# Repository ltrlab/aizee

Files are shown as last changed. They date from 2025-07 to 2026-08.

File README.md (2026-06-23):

# AIZEE — open-source mobile manipulation platform

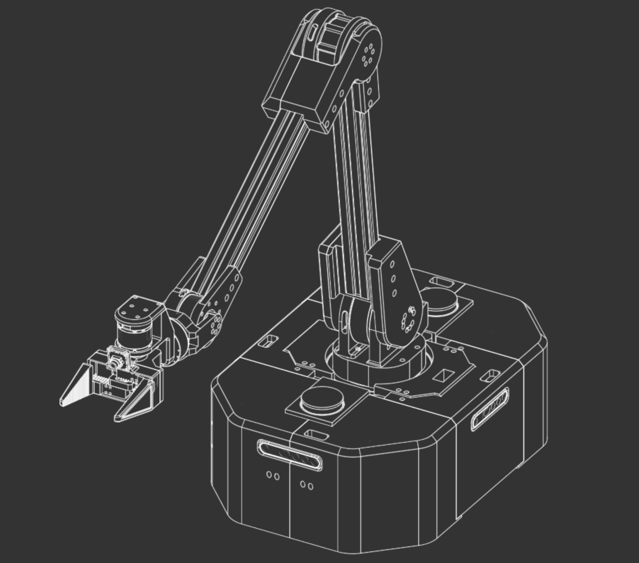
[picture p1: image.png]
AIZEE preview


AIZEE is a wheeled mobile manipulator with a 6-DoF arm, built for real-time
teleoperation, demonstration collection, and imitation-learning policies. It
pairs a deterministic Rust motor-control core with a Python teleop/learning
stack, all glued together over ZeroMQ.

- **CAD (OnShape):** https://cad.onshape.com/documents/191b8a861f2900918f30776f/w/8fcf08900b23701d0eff1c6a/e/fcb77dc7adbafb5b753006f3

> The platform runs in two physical configurations that share the same code and
> CAN bus: **rover mode** (drive wheels + arm) and **static mode** (arm only on a
> fixed stand, typically with the external scene camera). Optional subsystems
> auto-detect at runtime, so the same launch command works in either mode.

---

## Hardware

### Compute
- **NVIDIA Jetson Orin Nano** (JetPack 6.x) — the on-robot brain. Runs the Rust
  motor-control binary, the camera/UPS/display nodes, and the status dashboard.
  USB-CAN (gs_usb) adapter on `can1`; ZeroMQ for all inter-process messaging.
- **Operator / dev machine** — runs teleop, demonstration collection, and
  training. Drives the arm through a *leader* device (see below) and connects to
  the Jetson over one of three network paths.

### Actuation — 9× ROBSTRIDE motors (single CAN bus, `can1`)

| Joint | CAN ID | Motor | Role |
|---|:---:|:---:|---|
| left_wheel | 0x02 | ROBSTRIDE04 | drive wheel |
| right_wheel| 0x04 | ROBSTRIDE04 | drive wheel |
| swivel | 0x03 | ROBSTRIDE03 | base rotation (arm joint 0) |
| gantry_base| 0x05 | ROBSTRIDE04 | shoulder |
| gantry_mid | 0x06 | ROBSTRIDE03 | upper arm |
| gantry_end | 0x07 | ROBSTRIDE02 | elbow |
| wrist_pitch| 0x08 | ROBSTRIDE02 | wrist pitch |
| wrist_roll | 0x09 | ROBSTRIDE00 | wrist roll |
| gripper | 0x0A | ROBSTRIDE00 | gripper |

The arm is **7-DoF in software** (`swivel` + 6-DoF gantry, swivel-first
ordering). In static mode the two wheels are simply absent from the bus.

**Control loops** (`config/hardware_jetson_rover.yaml`):
- Arm: **400 Hz** (CAN-bus limited — ~280 µs per motor round-trip)
- Base (wheels + swivel): **100 Hz**
- Telemetry publish: **50 Hz**
- Watchdog: holds position if no command for **500 ms**

### Cameras
- **Gripper camera** — ELP-USBFHD01M-L21 USB UVC, color **1024×768 @ 30 fps**
  (MJPG), mounted on the gripper. Primary close-up training observation.
- **Scene camera** *(optional)* — Intel RealSense D435/D435i/D455, color +
  depth **640×480 @ 15 fps**, externally mounted for a wider workspace view with
  depth. Auto-detected at runtime: present ⇒ static mode (recorded), absent ⇒
  rover mode (hidden, not required).

### Other sensors & peripherals
- **2× SLAMTEC RPLiDAR A1M8** — 360° scan, driver in `rust/lidar_control`
  (optional; not enabled in all configurations).
- **UPS power monitor** — Waveshare INA219 over I²C, publishes battery
  voltage/current/% telemetry.
- **Tufty2040 status display** — RP2040 over USB CDC, on-robot status readout.
- **Wireless e-stop** — ESP32 ESP-NOW receiver bridged to ZMQ; broadcasts stop
  to all motors.

### Networking — three ways to reach the robot
| Path | Jetson address | Use |
|---|---|-----|
| LAN / WiFi client | `192.168.0.27` | production network (configured default) |
| USB-C ethernet | `10.42.0.1` | direct tether (NetworkManager shared link) |
| WiFi AP `aizee` | `192.168.50.1` | the robot broadcasts its own network (AP mode) |

The operator tools probe these **in priority order** and use the first that
answers, so the same command works whether you're on the LAN, tethered over
USB-C, or joined to the robot's own WiFi.

---

## Software

### Stack
- **Rust** — motor control, CAN protocol, deterministic control loops, CAN
  fault recovery.
- **Python 3.10+** — teleop, leader drivers, camera/UPS/display nodes,
  demonstration collection, policy training & inference.
- **ZeroMQ** — command/telemetry/camera pub-sub between host and Jetson.
- **Rerun** — real-time visualization and MCAP logging.

### Architecture
```
        Operator / dev machine
  ┌───────────────────────────────────┐
  │ leader arm (SO-101 / OpenRB-150 /  │
  │ Quest VR) · gamepad · M5 joystick  │
  │ collect_demo.py / teleop.py        │
  └───────────────┬───────────────────┘
                  │ ZMQ commands (~100 Hz)
                  │ path: 192.168.0.27 → 10.42.0.1 → 192.168.50.1
                  ▼
  ┌───────────────────────────────────────────────┐
  │              Jetson Orin Nano                   │
  │  motor_control (Rust)      400 Hz arm /100 Hz  │
  │    CAN bus · watchdog · fault recovery         │
  │      ├─ telemetry  PUB :5556  (50 Hz)          │
  │  camera_node (gripper UVC) PUB :5563           │
  │  camera_node (scene RGB-D) PUB :5564           │
  │  ups_node                  PUB :5562           │
  │  lidar_control             PUB :5561           │
  │  heartbeat dashboard       HTTP :8088          │
  └───────────────────────────────────────────────┘
```

### ZeroMQ / service ports
| Port | Type | Service | Payload |
|:----:|---|---|---|
| 5555 | SUB | motor_control | incoming motor commands |
| 5556 | PUB | motor_control | motor telemetry (state/pos/vel/torque/temp) |
| 5561 | PUB | lidar_control | LiDAR scans |
| 5562 | PUB | ups_node | battery telemetry |
| 5563 | PUB | gripper camera | color JPEG |
| 5573 | REP | gripper camera | runtime V4L2 control (GUI sliders) |
| 5564 | PUB | scene camera | color JPEG + Z16 depth |
| 8088 | HTTP | heartbeat | status/telemetry/log dashboard |

On-robot subsystems run as **systemd services** (`aizee-motor-control-rover`,
`aizee-gripper-cam`, `aizee-scene-cam`, `aizee-ups-monitor`, `aizee-heartbeat`,
`aizee-display`, …) and start on boot.

---

## Repository structure
```
aizee/
├── rust/
│   ├── motor_control/   # CAN driver + control loops (400 Hz arm, 100 Hz base) + recovery
│   ├── comms/           # ZeroMQ abstractions and message schemas
│   ├── lidar_control/   # RPLiDAR A1M8 dual-sensor driver
│   └── bindings/        # PyO3 Python bindings (reserved)
├── python/
│   ├── teleop/          # Leader drivers: SO-101, OpenRB-150, Quest VR + shared discovery
│   ├── nodes/           # Camera, UPS, ACT-policy inference nodes
│   ├── scripts/         # collect_demo (GUI), teleop, leader monitor, episode replay/view
│   ├── training/        # ACT + ACT-JEPA policy training and dataset utilities
│   ├── tools/           # heartbeat_server.py (status dashboard)
│   └── web/             # WebXR client for Quest teleop
├── config/              # Hardware YAML, calibration, systemd/udev units
├── scripts/             # Deploy, setup, and diagnostic shell scripts
├── firmware/            # Tufty2040 display, wireless e-stop, OpenRB-150 leader
├── urdf/                # Robot URDF (from OnShape)
├── episodes/            # Recorded demonstrations (HDF5)
├── docs/                # Quick-start, subsystem, and learning-pipeline docs
└── tests/               # Test suite
```

---

## Getting started

### Prerequisites
- NVIDIA Jetson Orin Nano with JetPack 6.x
- Rust toolchain (stable) and Python 3.10+
- A leader device for teleop (SO-101, OpenRB-150, or a Meta Quest headset) —
  optional; the stack also runs leaderless and hot-plugs a leader later.

### Install & deploy
```bash
git clone https://github.com/ltrlab/aizee.git
cd aizee
pip install -r requirements.txt

# Deploy to the Jetson (motor control + services)
./scripts/deploy_jetson_rover.sh

# Deploy optional subsystems
./scripts/deploy_gripper_camera.sh
./scripts/deploy_scene_cam.sh      # static mode only
./scripts/deploy_heartbeat.sh
```

### Check the robot is up
Open the **heartbeat dashboard** — service status, recent logs, host metrics,
and live robot telemetry (motors, batteries, cameras) on one page:
```
http://10.42.0.1:8088     # over USB-C ethernet
http://192.168.50.1:8088  # over the robot's WiFi AP
```

### Teleoperate
```bash
# Full teleop (gamepad / keyboard)
python python/teleop/teleop.py

# SO-101 leader-arm teleop
python python/scripts/so101_teleop.py --port /dev/ttyACM0

# Live leader position/limits monitor (auto-detects SO-101 or OpenRB-150)
python python/scripts/leader_monitor.py
```

### Collect demonstrations & train
```bash
# Record demos — leader auto-detected on USB; rover-IP auto-resolved;
# scene cam auto-detected (omit it for rover mode)
python python/scripts/collect_demo.py --gui

# Force a specific leader kind
python python/scripts/collect_demo.py --gui --leader openrb

# Train an ACT policy on collected episodes
python python/training/train.py --data-dir episodes/ --output-dir checkpoints/

# (Experimental) ACT-JEPA — adds a self-supervised world-model objective
python python/training/train_jepa.py --data-dir episodes/ --output-dir checkpoints/

# Run a trained policy on the arm
python python/nodes/act_policy_node.py --checkpoint checkpoints/act_epoch_0100.pt

# Visualize / replay a recorded episode
python python/scripts/view_episode.py episodes/episode_0001.hdf5
python python/scripts/episode_replay_live.py episodes/episode_0001.hdf5
```

### Leader devices
All three present the same 7-DoF interface, so teleop/collection code is
leader-agnostic once connected:
- **SO-101** — Feetech STS3215 servo arm over USB serial (original leader).
- **OpenRB-150 + Dynamixel XL330** — drop-in alternative; also carries an
  M5Stack Joystick2 for drive + record-toggle.
- **Quest VR** — Meta Quest Pro driving the arm via a WebXR client (`python/web`).

---

## Data format
Demonstrations are written as HDF5:
- **v4** — gripper camera + joint states/commands/torques + timestamps.
- **v5** — v4 **plus** `observations/images/scene` and `timestamps/camera_scene`
  when the scene camera is present. v4 episodes remain fully loadable.

---

## Status
All major subsystems are deployed and operational:
- ✅ Rust motor control (400 Hz arm / 100 Hz base) with CAN fault recovery
- ✅ Drive wheels + 6-DoF arm on one CAN bus (rover & static modes)
- ✅ Teleop via SO-101, OpenRB-150, and Quest VR leaders (7-DoF)
- ✅ On-Jetson cameras: ELP UVC gripper + RealSense scene (udev auto-start)
- ✅ Demonstration collection with camera sync (HDF5 v4/v5) + GUI
- ✅ ACT policy training & inference; ACT-JEPA training (experimental)
- ✅ Episode replay with safety clamping
- ✅ UPS battery monitoring, Tufty status display, wireless e-stop
- ✅ WiFi AP mode + status/telemetry dashboard
- ◻️ 2× RPLiDAR A1M8 integration (driver present; not always enabled)

See [docs/PHASES.md](docs/PHASES.md) for the full roadmap.

---

## Documentation
- [docs/quickstart/](docs/quickstart/) — connect, run, and post-reboot guides
- [docs/subsystems/](docs/subsystems/) — motors, cameras, leaders, UPS, display, LiDAR
- [docs/LEARNING_PIPELINE.md](docs/LEARNING_PIPELINE.md) — calibration → collection → training → deployment
- [docs/PHASES.md](docs/PHASES.md) — implementation roadmap

## License
MIT — see [LICENSE](LICENSE).

## Contributing
Active research project — contributions welcome.

## Contact
LTRLABS — [GitHub](https://github.com/ltrlab)

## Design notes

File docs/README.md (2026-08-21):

# AIZEE Documentation

Technical documentation for the AIZEE mobile manipulation platform.

## Getting started
- **[quickstart/FRESH_JETSON_SETUP.md](quickstart/FRESH_JETSON_SETUP.md)** — blank Orin Nano → validated robot (`scripts/bootstrap_jetson.sh` + the `/setup` wizard)
- **[quickstart/JETSON_QUICK_START.md](quickstart/JETSON_QUICK_START.md)** — connect to the robot and run teleop / data collection (daily reference)
- **[quickstart/QUICK_START_AFTER_REBOOT.md](quickstart/QUICK_START_AFTER_REBOOT.md)** — post-reboot verification, service management, troubleshooting

> First check after connecting: the **heartbeat dashboard** at `http://<jetson-ip>:8088`
> (e.g. `http://10.42.0.1:8088` over USB-C, `http://192.168.50.1:8088` over the `aizee` AP) —
> service status, recent logs, host metrics, and live robot telemetry on one page.

## Subsystems
- **[subsystems/MOTORS.md](subsystems/MOTORS.md)** — 9× ROBSTRIDE on `can1`; roster/CAN IDs, control loops, parameter read/write protocol
- **[subsystems/CAMERAS.md](subsystems/CAMERAS.md)** — gripper UVC (primary) + optional RealSense scene cam, both on the Jetson
- **[subsystems/OPENRB_LEADER.md](subsystems/OPENRB_LEADER.md)** — OpenRB-150 + Dynamixel XL330 leader: firmware, setup, wire protocol
- **[subsystems/UPS.md](subsystems/UPS.md)** — INA219 battery monitoring
- **[subsystems/TUFTY2040.md](subsystems/TUFTY2040.md)** — Tufty2040 status display
- **[subsystems/LIDAR.md](subsystems/LIDAR.md)** — 2× RPLiDAR A1M8 (optional)

## Learning
- **[LEARNING_PIPELINE.md](LEARNING_PIPELINE.md)** — end-to-end guide: calibration → data collection → training → evaluation → deployment
- **[learning/RESEARCH_PLAN.md](learning/RESEARCH_PLAN.md)** — research direction and experiment plan

## Roadmap
- **[PHASES.md](PHASES.md)** — implementation status and roadmap

## Reference
- **[MINERVA_ACTUATORS.md](MINERVA_ACTUATORS.md)** — Cubemars actuator plan for the Minerva humanoid torso + cost/weight comparison vs the AIZEE Robstrides
- ROBSTRIDE motor manuals: `RS00`/`RS02`/`RS03`/`RS04` User Manual PDFs (this directory)
- [../rust/motor_control/README.md](../rust/motor_control/README.md) — motor control crate
- [../rust/lidar_control/README.md](../rust/lidar_control/README.md) — LiDAR control crate
- [../tests/README.md](../tests/README.md) — test suite
- [../README.md](../README.md) — project overview & hardware specs

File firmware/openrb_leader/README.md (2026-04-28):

# OpenRB-150 Leader Arm Firmware

Reads 7× Dynamixel XL330-M077-T servos and exposes them to the host over
USB-CDC for use as the AIZEE leader arm. See
[../../docs/subsystems/OPENRB_LEADER.md](../../docs/subsystems/OPENRB_LEADER.md)
for full documentation including wire protocol and setup procedure.

## Build / upload

```bash
pip install --user platformio
pio run -e openrb150 -t upload --upload-port COM4 -d firmware/openrb_leader
```

The `openrb150_bsp/` folder vendors the Robotis OpenRB-150 SAMD Arduino
core (LGPL-2.1) so the build is self-contained — no Arduino IDE required.

## Layout

```
firmware/openrb_leader/
├── platformio.ini              # PlatformIO build config (overrides framework with the vendored BSP)
├── boards/openrb150.json       # Custom PIO board definition for OpenRB-150
├── src/main.cpp                # Sketch — wire protocol, sync-read, setup commands
├── openrb150_bsp/              # Vendored Robotis OpenRB-150 Arduino SAMD core
└── README.md                   # This file
```

## Host-side scripts

| Script | Purpose |
|---|---|
| `python/scripts/openrb_setup_arm.py` | First-time servo ID assignment (1..7) |
| `python/scripts/openrb_calibrate.py` | Per-joint min/max calibration |
| `python/scripts/leader_monitor.py` | Live position + limits monitor (also drives `C` key for sequential centering) |

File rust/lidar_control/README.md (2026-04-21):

# lidar_control - RPLiDAR A1M8 Interface

Rust service for interfacing with RPLiDAR A1M8 sensors on the AIZEE rover.

## Overview

This crate provides a standalone service that:
- Interfaces with two RPLiDAR A1M8 sensors via USB serial
- Publishes scan data via ZeroMQ on port 5561
- Runs independently from motor control for failure isolation
- Supports automatic reconnection on USB disconnect
- Uses async Tokio with `spawn_blocking` for serial I/O

## Architecture

```
┌─────────────────────────────────────────────────────┐
│                  lidar_control                      │
│                                                     │
│  ┌──────────────┐      ┌──────────────┐           │
│  │ LidarScanner │      │ LidarScanner │           │
│  │   (front)    │      │   (back)     │           │
│  └──────┬───────┘      └──────┬───────┘           │
│         │                     │                    │
│         │ spawn_blocking      │ spawn_blocking     │
│         │                     │                    │
│         └─────────┬───────────┘                    │
│                   │                                │
│            mpsc::channel                           │
│                   │                                │
│                   ▼                                │
│          ┌─────────────────┐                       │
│          │  Main Loop      │                       │
│          │  (async tokio)  │                       │
│          └────────┬────────┘                       │
│                   │                                │
│                   ▼                                │
│          ┌─────────────────┐                       │
│          │   ZMQ PUB       │                       │
│          │   tcp://*:5561  │                       │
│          └─────────────────┘                       │
└─────────────────────────────────────────────────────┘
```

## Message Format

Published as `TelemetryMessage` JSON on ZMQ port 5561:

```json
{
  "timestamp": 1707584123.456,
  "motors": {},
  "battery_voltage": null,
  "lidar_scans": [
    {
      "sensor_id": "lidar_front",
      "angle_min": 0.0,
      "angle_max": 6.283185,
      "angle_increment": 0.017453,
      "range_min": 0.15,
      "range_max": 12.0,
      "ranges": [1.23, 2.45, 3.67, ...],
      "intensities": [255, 248, 250, ...]
    },
    {
      "sensor_id": "lidar_back",
      "angle_min": 0.0,
      "angle_max": 6.283185,
      "angle_increment": 0.017453,
      "range_min": 0.15,
      "range_max": 12.0,
      "ranges": [0.89, 1.56, 2.34, ...],
      "intensities": [252, 255, 249, ...]
    }
  ]
}
```

## Configuration

Configured via `config/hardware_jetson_rover.yaml`:

```yaml
lidars:
  - id: lidar_front
    device: /dev/rplidar_front
    scan_mode: standard

  - id: lidar_back
    device: /dev/rplidar_back
    scan_mode: standard

network:
  device:
    zmq:
      lidar_pub: "tcp://*:5561"
```

## Building

```bash
# Build release binary
cargo build --release -p lidar_control

# Binary location
./target/release/lidar_control
```

## Running

```bash
# Set config path
export AIZEE_CONFIG=/path/to/config/hardware_jetson_rover.yaml

# Set log level (optional)
export RUST_LOG=info

# Run
./target/release/lidar_control
```

## Dependencies

- **rplidar_drv** (0.6): RPLiDAR SDK bindings
- **serialport** (4.2): Cross-platform serial port access
- **tokio**: Async runtime
- **zmq**: ZeroMQ bindings
- **comms**: Internal crate (message definitions)

## Error Handling

The service is designed for robustness:

1. **Independent sensors**: One sensor failing doesn't crash the other
2. **Auto-reconnect**: USB disconnect triggers reconnection attempts
3. **Graceful degradation**: Continues operating with one sensor if other fails
4. **Blocking I/O isolation**: Serial I/O runs in `spawn_blocking` threads

## Testing

Subscribe to telemetry with Python:

```python
import zmq

ctx = zmq.Context()
sub = ctx.socket(zmq.SUB)
sub.connect("tcp://192.168.0.27:5561")
sub.subscribe(b"")

msg = sub.recv_json()
print(f"Received {len(msg['lidar_scans'])} scans")
```

## Deployment

See `docs/subsystems/LIDAR.md` for complete deployment guide.

## Performance

- **Scan rate**: ~5.5Hz (natural RPLiDAR A1M8 rate)
- **Publish rate**: 5Hz (200ms interval)
- **Points per scan**: 350-365
- **CPU usage**: <5% per sensor
- **Memory**: ~8-12 MB

## Module Structure

- `main.rs`: Tokio runtime, ZMQ publisher, main control loop
- `scanner.rs`: `LidarScanner` struct, hardware interface, reconnect logic

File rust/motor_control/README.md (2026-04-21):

# AIZEE Motor Control

Low-level CAN bus motor control for ROBSTRIDE actuators with deterministic control loops.

## Features

- **ROBSTRIDE Protocol**: Complete implementation of RS03-EN CAN protocol
- **Deterministic Control**: 1kHz arm control loop, 100Hz base control loop
- **Safety Features**: Watchdog timeout, soft limits, emergency stop
- **ZeroMQ Interface**: JSON commands over pub/sub sockets
- **Real-time Telemetry**: 50Hz motor state publishing

## Building

```bash
cd rust/motor_control
cargo build --release
```

## CAN Interface Setup

### For CANable/slcan Adapters

```bash
# Load slcan kernel module
sudo modprobe slcan

# Attach slcan device (replace /dev/ttyACM0 with your adapter)
sudo slcand -o -c -s8 /dev/ttyACM0 can0

# Bring up the interface
sudo ip link set can0 up

# Verify
ip link show can0
```

### For SocketCAN Native Interfaces

On the Jetson Orin Nano (production), motors are on `can1`:

```bash
# Set bitrate to 1 Mbps
sudo ip link set can1 type can bitrate 1000000

# Bring up the interface
sudo ip link set can1 up

# Verify
ip link show can1
```

## Running

```bash
# Set config path (optional, defaults to config/hardware.yaml)
export AIZEE_CONFIG=config/hardware.yaml

# Run motor controller
./target/release/motor_control
```

## Configuration

Edit `config/hardware.yaml` to match your hardware:

```yaml
motors:
  wheels:
    - id: left_wheel
      can_id: 0x01
      type: ROBSTRIDE04
      # ...

can:
  interface: can1  # Jetson production: can1; RPi4 arm module: can0

network:
  device:  # accepts "jetson" as alias for backward compatibility
    zmq:
      command_sub: "tcp://*:5555"
      telemetry_pub: "tcp://*:5556"
```

## Command Interface

Send JSON commands to `tcp://localhost:5555`:

### Enable Motors
```json
{
  "type": "enable",
  "motor_ids": ["left_wheel", "right_wheel"]
}
```

### Drive Base
```json
{
  "type": "drive",
  "linear": 0.5,
  "angular": 0.2
}
```

### Move Arm
```json
{
  "type": "arm_joints",
  "positions": [0.1, 0.5, -0.3],
  "velocities": [0.0, 0.0, 0.0]
}
```

### Emergency Stop
```json
{
  "type": "emergency_stop"
}
```

## Telemetry Format

Receive JSON telemetry from `tcp://localhost:5556`:

```json
{
  "timestamp": 1234567890.123,
  "motors": {
    "left_wheel": {
      "position": 1.5,
      "velocity": 0.5,
      "torque": 2.1,
      "temperature": 45.0,
      "error": null
    }
  }
}
```

## Testing

Use the Python test script:

```bash
# Interactive mode
python python/teleop/simple_test.py

# Automated test sequence
python python/teleop/simple_test.py auto
```

## Troubleshooting

### CAN Interface Not Found

```bash
# Check available interfaces
ip link show

# For slcan adapters, check USB connection
lsusb
ls /dev/ttyACM*
```

### Permission Denied

```bash
# Add user to dialout group (for USB-CAN adapters)
sudo usermod -a -G dialout $USER

# Or run with sudo (not recommended for production)
sudo ./target/release/motor_control
```

### Motor Not Responding

1. Check CAN wiring (CAN-H, CAN-L, 120Ω termination)
2. Verify motor power (40V supply connected)
3. Check motor CAN ID matches config
4. Use `candump can1` to see CAN traffic (Jetson) or `candump can0` (RPi4 arm module)
5. Test with single motor first

### High CPU Usage

The 1kHz control loop is CPU-intensive. Ensure:
- Running on performance governor: `sudo cpufreq-set -g performance`
- No other heavy processes running
- Consider lowering arm_frequency in config if needed

## Architecture

```
┌─────────────────────┐
│  ZeroMQ Commands    │  (TCP:5555)
│  from Teleop        │
└──────────┬──────────┘
           │
           ▼
┌─────────────────────────────────┐
│  Motor Control (main.rs)        │
│  ┌──────────────────────────┐  │
│  │  Command Handler         │  │
│  └──────────┬───────────────┘  │
│             │                   │
│  ┌──────────▼───────────────┐  │
│  │  Safety Monitor          │  │
│  │  - Watchdog              │  │
│  │  - Soft Limits           │  │
│  │  - Error Detection       │  │
│  └──────────┬───────────────┘  │
│             │                   │
│  ┌──────────▼───────────────┐  │
│  │  Control Loop            │  │
│  │  - Arm: 1kHz             │  │
│  │  - Base: 100Hz           │  │
│  └──────────┬───────────────┘  │
│             │                   │
│  ┌──────────▼───────────────┐  │
│  │  ROBSTRIDE Protocol      │  │
│  │  (robstride.rs)          │  │
│  └──────────┬───────────────┘  │
└─────────────┼───────────────────┘
              │
              ▼
        ┌──────────┐
        │  CAN Bus │  (SocketCAN)
        └──────────┘
              │
        ┌─────┴──────┐
        ▼            ▼
    [Motor 1]   [Motor 2] ...
```

## Protocol Details

Based on ROBSTRIDE RS03-EN specification:

- **CAN ID Format**: Extended 29-bit
  - Bits 0-7: Motor ID
  - Bits 8-15: Host ID (0xAA)
  - Bits 16-20: Error flags
  - Bits 24-28: Message type

- **Message Types**:
  - 0: Info
  - 1: Control (position/velocity/torque)
  - 2: Feedback
  - 3: Enable
  - 4: Disable
  - 6: Zero Position
  - 17: Read Parameter
  - 18: Write Parameter

- **Feedback Format** (8 bytes):
  - Bytes 0-1: Position (uint16, -4π to 4π)
  - Bytes 2-3: Velocity (uint16, model-dependent range)
  - Bytes 4-5: Torque (uint16, model-dependent range)
  - Bytes 6-7: Temperature (uint16, °C × 10)

See `robstride.rs` for complete implementation.

## License

MIT License - see top-level LICENSE file.

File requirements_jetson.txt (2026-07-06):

# AIZEE on-device (Jetson) Python dependencies.
#
# Installed into the SYSTEM python3 (services run /usr/bin/python3, no venv)
# by scripts/setup_jetson.sh via `python3 -m pip install --user`.
#
# NOT listed here on purpose:
#   opencv       -> use JetPack's apt package `python3-opencv` (CUDA build;
#                   a pip opencv-python would shadow it and pull numpy 2.x)
#   smbus        -> apt package `python3-smbus` (UPS/INA219 on i2c bus 7)
#   pyrealsense2 -> tried separately by setup_jetson.sh; pip wheels for
#                   aarch64 are hit-or-miss. Fallback: scripts/build_librealsense_rsusb.sh

# Core communication (every node + heartbeat telemetry)
pyzmq>=25.0.0
msgpack>=1.0.5

# JetPack's apt python3-opencv is built against numpy 1.x -- keep below 2.
numpy>=1.24.0,<2

# Gripper camera node (JPEG encode) + camera_node
Pillow>=10.0.0

# Tufty display node + e-stop bridge + OpenRB serial
pyserial>=3.5

# Config loading (hardware_*.yaml)
pyyaml>=6.0

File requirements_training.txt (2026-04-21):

# AIZEE ACT Training Requirements
# Install on dev machine (Windows + GPU) in addition to requirements.txt:
#
#   pip install -r requirements.txt
#   pip install -r requirements_training.txt

# Deep learning framework — GPU-accelerated training on dev machine
# Install the correct CUDA variant for your GPU, e.g.:
#   pip install torch torchvision --index-url https://download.pytorch.org/whl/cu121
torch>=2.1.0
torchvision>=0.16.0   # ResNet18 pretrained weights via torchvision.models

# HDF5 episode storage
h5py>=3.9.0

# Tensor reshape utilities (used in transformer attention operations)
einops>=0.6.0

# ---------------------------------------------------------------------------
# Jetson Orin inference note
# ---------------------------------------------------------------------------
# PyTorch for Jetson Orin MUST be installed from NVIDIA's JetPack wheel —
# NOT from PyPI — to get CUDA GPU support.
#
# 1. Install JetPack 6.x via SDK Manager (or apt):
#    sudo apt install nvidia-jetpack
#
# 2. Install the matching PyTorch wheel from NVIDIA:
#    https://developer.download.nvidia.com/compute/redist/jp/v61/pytorch/
#
#    Example (JetPack 6.1, Python 3.10):
#    pip install torch-2.3.0-cp310-cp310-linux_aarch64.whl
#
# 3. torchvision and h5py can be installed from PyPI normally:
#    pip install torchvision h5py einops
#
# 4. torchvision may need to be built from source on aarch64 if no
#    matching wheel is available:
#    pip install torchvision --no-binary torchvision

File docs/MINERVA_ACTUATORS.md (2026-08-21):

# Minerva Actuator Selection & Sourcing

Actuator plan for the **Minerva** humanoid torso (a sibling build to AIZEE). Minerva is
an 18-DoF platform: a 2-DoF waist (swivel + forward/back lean), a 2-DoF neck, and two
6-DoF arms each with a gripper. Drive is dual CAN bus chains, MIT-mode control, 48 V.

Last priced: 2026-07-27. Prices are MSRP with integrated driver board and drift; re-check before ordering.

## Joint layout (18 actuators)

| Subsystem | Joints | Count |
|---|---|---|
| Waist | swivel (yaw), lean (pitch) | 2 |
| Neck | 2-DoF | 2 |
| Arms (x2) | shoulder pitch, shoulder roll, elbow, wrist flex, wrist pitch, wrist roll, gripper | 14 |

Check: (6 DoF + gripper) x 2 arms = 14, waist 2, neck 2 = **18**.

## Recommended Cubemars BOM

| Model | Joint roles | Peak / rated Nm | Ratio | Wt ea | Price ea | Qty | Link |
|---|---|---|---|---|---|-----|---|
| AK80-64 | torso lean + 2 shoulder pitch | 120 / 48 | 64:1 | 850 g | ~$989.90 | 3 | https://store.cubemars.com/products/ak80-64 |
| AK60-39 V3.0 | 2 shoulder roll | 72 / 24 | 39:1 | 750 g | $448.90 | 2 | https://store.cubemars.com/products/ak60-39-v3-0 |
| AK10-9 V3.0 | torso swivel + 2 elbows | 53 / 18 | 9:1 | 896 g | $798.90 | 3 | https://store.cubemars.com/products/ak10-9-v3-0-kv60 |
| AK70-10 | 4x wrist flex/pitch | 24.8 / 8.3 | 10:1 | 521 g | $398.90 | 4 | https://store.cubemars.com/products/ak70-10 |
| AK40-10 KV170 | 2 wrist roll + 2 grippers + 2 neck | 4.1 / 1.3 | 10:1 | 185 g | $99.90 | 6 | https://store.cubemars.com/products/ak40-10-kv170 |

**Totals: 18 units, ~$8,459, ~9.93 kg** (actuators only).

Notes:
- All AK models currently show sold out on the official store; resellers (DigiKey, RobotShop, Oz Robotics) carry stock at similar or higher prices.
- AK80-64 listing showed a $889.90 / $989.90 sale ambiguity, so budget the shoulder/lean trio at $2,670 to $2,970.
- The 6x AK40-10 (185 g, $99.90) are the value pick; pushing neck, wrist roll, and grippers onto them wins on both weight and cost.

### Shoulder-roll note
AK60-39 (72 Nm) was chosen over a second AK80-64 for the shoulder-roll (abduction)
joint: still high-torque, but 100 g lighter and ~$540 cheaper each. Swap to AK80-64 if
maximum payload margin is wanted (adds ~200 g total for the pair, +48 Nm peak each).

## Comparison vs AIZEE Robstrides

Per-joint equivalence (Cubemars pick vs the Robstride playing the same role on AIZEE):

| Role | Cubemars | Peak/rated Nm | Ratio | Wt | Robstride | Peak/rated Nm | Ratio | Wt |
|---|---|---|---|----|---|---|---|----|
| Shoulder pitch / lean | AK80-64 | 120 / 48 | 64:1 | 850 g | RS04 | 120 / 40 | 9:1 | 1420 g |
| Shoulder roll | AK60-39 | 72 / 24 | 39:1 | 750 g | (RS03 nearest) | 60 / 21 | 9:1 | 900 g |
| Torso swivel / elbow | AK10-9 | 53 / 18 | 9:1 | 896 g | RS03 | 60 / 21 | 9:1 | 900 g |
| Wrist flex / pitch | AK70-10 | 24.8 / 8.3 | 10:1 | 521 g | RS02 | 17 / 7 | 7.75:1 | 380 g |
| Wrist roll / gripper / neck | AK40-10 | 4.1 / 1.3 | 10:1 | 185 g | RS00 | 14 / 5 | 10:1 | 310 g |

Full-build totals, same 18-joint layout mapped to each vendor's best fit:

| | Cubemars | Robstride |
|--|---|---|
| Torso lean + shoulder pitch | 3x AK80-64 | 3x RS04 |
| Shoulder roll | 2x AK60-39 | 2x RS03 |
| Torso swivel + elbows | 3x AK10-9 | 3x RS03 |
| Wrist flex/pitch | 4x AK70-10 | 4x RS02 |
| Wrist roll + grippers + neck | 6x AK40-10 | 6x RS00 |
| Actuator cost | ~$8,459 | ~$2,100 |
| Actuator weight | ~9.93 kg | ~12.1 kg |

Robstride prices from China retail (RS04 CNY 1199, RS03 CNY 999, RS02 CNY 699, RS00 CNY 598
at ~7.15 CNY/USD); US resellers run higher.

### Takeaways
- Robstride is ~4x cheaper but ~2.2 kg heavier, almost all from the three 1.42 kg RS04s.
- Cubemars buys weight savings and US distribution/support, not raw performance. On spec
  the Robstrides match or beat the Cubemars picks at every joint except distal weight.
- The RS04 shoulder is the clear performance winner: same 120 Nm peak as the AK80-64 but
  at 9:1 (fast, back-drivable) vs 64:1 (slow, stiff). Cubemars has no 9:1 / 120 Nm unit.
- The Cubemars build only pencils out as a fully-sponsored kit (credited YouTube build):
  lighter arms + vendor support at no hardware cost.

## Sponsorship status
Approached CubeMars (Heidi, Global Marketing & Sales, lmh@cubemars.com) for a full
18-unit hardware sponsorship in exchange for a sponsored YouTube build video and CubeMars
credit on all Minerva posts. Awaiting their response on the requested set.

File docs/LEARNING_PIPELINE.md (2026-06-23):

# Learning Pipeline

End-to-end guide for collecting demonstrations, training an ACT policy, validating it offline, and deploying it on the robot.

## Overview

```
1. Calibrate        so101_calibrate.py / openrb_calibrate.py   (one-time, per leader)
2. Collect demos    collect_demo.py --gui                       (record HDF5 episodes via a leader)
3. Train            train.py                                    (ACT model on collected episodes)
4. Evaluate         evaluate_policy.py                          (offline replay through model, compare to GT)
5. Deploy           act_policy_node.py                          (live 20 Hz inference loop on Jetson)
```

## Prerequisites

| Component | Purpose |
|---|---|
| Jetson running `aizee-motor-control-rover` | CAN bus motor control + ZMQ telemetry |
| Gripper camera streaming | ELP UVC `:5563` — primary training observation (1024×768 color) |
| Scene camera (optional) | Intel RealSense `:5564` — wider RGB-D view, auto-detected |
| A leader device | SO-101, OpenRB-150, or Quest VR — for teleoperation during recording |
| `pip install -r requirements.txt` | h5py, torch, rerun-sdk, etc. |
| Leader calibration in `config/` | e.g. `so101_calibration.json`, `openrb_calibration.json` |

The robot is reachable on three network paths (probed in priority order):
`192.168.0.27` (LAN/WiFi) → `10.42.0.1` (USB-C ethernet) → `192.168.50.1` (the robot's WiFi AP).
SSH with `ssh -i ssh-keys/aizee_rover_id ltr@<ip>`. The heartbeat dashboard is at `:8088`.

Both cameras run on the Jetson. The previous stereo D435 wrist pair and the
RPi4 D455 camera nodes have been retired — episodes and the model are
single-camera (gripper), with the scene cam recorded as an optional extra.

---

## 1. Calibration

The leader arm must be calibrated once so its joint angles map correctly to the
AIZEE arm joints. Re-calibrate if the leader is physically modified or the
mapping drifts. Use the calibrator that matches your leader:

```bash
# SO-101 (Feetech STS3215)
python python/scripts/so101_calibrate.py --port COM4      # writes config/so101_calibration.json

# OpenRB-150 + Dynamixel XL330
python python/scripts/openrb_calibrate.py --port COM4     # writes config/openrb_calibration.json
```

(The Quest VR leader is driven by WebXR/IK and does not use a per-joint
servo calibration file.)

Each calibrator walks through each joint interactively and writes a per-leader
calibration JSON containing per-joint:

| Field | Meaning |
|---|---|
| `id` | Servo ID on the leader |
| `aizee` | Corresponding AIZEE joint name |
| `rad_min` / `rad_max` | Joint travel range in radians |
| `zero_offset` | Radians subtracted before direction multiply |
| `direction` | `+1` or `-1` sign flip between leader and AIZEE conventions |

**Leader → AIZEE joint mapping (SO-101 example):**

| SO-101 | AIZEE |
|---|---|
| shoulder_pan | swivel |
| shoulder_lift | gantry_base |
| elbow_flex | gantry_mid |
| wrist_flex | gantry_end |
| wrist_yaw | wrist_pitch |
| wrist_roll | wrist_roll |
| gripper | gripper |

The AIZEE arm is **7-DoF, swivel-first**:
`swivel, gantry_base, gantry_mid, gantry_end, wrist_pitch, wrist_roll, gripper`.

The follower motors themselves can be zeroed/gravity-tuned separately with
`python python/scripts/robstride_calibrate.py` (writes `config/robstride_calibration.json`).

**Quick check:** after calibrating, use `python python/scripts/so101_teleop.py --port COM4`
or `python python/scripts/leader_monitor.py` to verify the mapping looks correct
before recording episodes.

---

## 2. Data Collection

### Starting the recorder

The recommended entry point is the GUI, with the leader, rover IP, and scene
camera all auto-detected:

```bash
# Auto-detect everything (leader on USB, rover IP, scene cam)
python python/scripts/collect_demo.py --gui

# Force a specific leader kind (otherwise auto: SO-101 then OpenRB-150)
python python/scripts/collect_demo.py --gui --leader openrb
python python/scripts/collect_demo.py --gui --leader so101

# Specify output directory
python python/scripts/collect_demo.py --gui --output-dir episodes/pick_task

# Dry-run (no files saved)
python python/scripts/collect_demo.py --gui --dry-run

# Terminal renderer instead of the Qt GUI (omit --gui)
python python/scripts/collect_demo.py
```

Leader selection (`--leader`) defaults to `auto`, which probes for an SO-101
then an OpenRB-150 on USB. The Quest VR leader is added/removed at runtime from
the GUI. The rover ZMQ endpoints auto-resolve across the three network paths,
and the scene cam is subscribed/recorded only when present.

Commonly used CLI arguments:

| Argument | Default | Description |
|---|---|---|
| `--gui` | off | Launch the PySide6 control panel (embeds the Rerun web viewer) |
| `--leader` | `auto` | `auto` \| `so101` \| `openrb` — which physical leader to start with |
| `--port` | None | Leader serial port (optional; auto-detected when omitted) |
| `--baud` | 1000000 | Leader baud rate |
| `--calib` | per-leader default | Leader calibration JSON |
| `--cmd` / `--telem` | rover defaults | ZMQ command / telemetry endpoints (auto-repointed across networks) |
| `--gripper-cam` | `tcp://192.168.0.27:5563` | Gripper camera (ELP UVC) endpoint |
| `--scene-cam` | `tcp://192.168.0.27:5564` | Scene camera (RealSense RGB-D); empty string disables it |
| `--output-dir` | `episodes` | Output directory |
| `--max-steps` | 10000 | Max frames per episode |
| `--image-size` | `768x1024` | Image resolution H×W (matches gripper-cam capture) |
| `--max-delta` | 0.3 | Per-step safety clamp (rad) |
| `--task-tag` | `""` | Task label written as an episode attr |
| `--no-rerun` | off | Disable the Rerun live preview |
| `--dry-run` | off | Don't save anything |

### Controls (terminal mode)

| Key | Action |
|---|---|
| **E** | Enable motors — starts TRACKING (with leader) or HOLD (without) |
| **I** | Idle — enable with zero torque, arm floats freely |
| **H** | Hold — freeze target at current actual position |
| **R** | Toggle recording on/off (TRACKING only) |
| **X** | Soft shutdown — hold 1 s, return to zero, disable |
| **Z** | Capture current leader pose as zero reference |
| **M** | Mirror — set zero offset so current leader pose → current arm pose |
| **P** | Save current arm position as ready pose (`config/ready_pose.json`) |
| **Q** | Quit (Ctrl-C also works) |
| **WASD** | Drive wheels (wheels enable with the arm) |

Gamepad: A=enable, B=shutdown/cancel, Start=hold, Back=quit, left stick=drive.
The M5Stack Joystick2 on the OpenRB-150 leader also drives the wheels and its
button toggles recording.

### Recording workflow

1. **Position the arm** — press **I** to idle (arm floats), physically place it at the task starting pose.
2. **Enable tracking** — press **E**. The arm now follows the leader.
3. **Start recording** — press **R**. The status line shows `[REC]` and the frame counter.
4. **Perform the task** — move the leader through the desired motion.
5. **Stop recording** — press **R** again. The episode is auto-saved as `episode_XXXX.hdf5`.
6. **Repeat** — record as many episodes as needed. Files are auto-numbered.

Recording samples at **20 Hz** (the main control loop runs at 30 Hz but sub-samples). A frame is only captured when the gripper camera is fresh (< 500 ms old) and telemetry is available. Stale frames are dropped and counted.

Camera images are decoded in a background thread so JPEG parsing doesn't delay motor commands. Episode saving is also backgrounded so gzip compression doesn't block the UI.

### Episode HDF5 format (v4 / v5)

Episodes are written with `format_version=4`, or `format_version=5` when the
scene camera is present (the extra scene fields below are appended). v4 episodes
remain fully loadable by the training/eval tools.

```
episode_XXXX.hdf5
├── attrs:
│     hz=20
│     format_version=4            # 5 when the scene cam is recorded
│     arm_joints="swivel,gantry_base,gantry_mid,gantry_end,wrist_pitch,wrist_roll,gripper"
│     action_space="absolute"
│     task_tag, notes, collected_at
├── observations/
│   ├── qpos          float32  [T, 7]    actual motor positions (swivel = column 0)
│   ├── qcmd          float32  [T, 7]    commanded positions (optional)
│   ├── torques       float32  [T, 7]    motor torques (optional)
│   └── images/
│       ├── gripper   uint8    [T, 768, 1024, 3]   ELP UVC (primary observation)
│       └── scene     uint8    [T, 480, 640, 3]    RealSense color — v5 only
├── actions           float32  [T, 7]    = qcmd shifted one step (next-step target)
└── timestamps/
    ├── telem          float64  [T]
    ├── camera_gripper float64  [T]
    └── camera_scene   float64  [T]      v5 only
```

**Actions** are derived from one-step-ahead commanded positions (`qcmd` shifted by one, last step repeated). This is what the controller actually targeted next, not the raw leader position — avoids gravity sag artifacts. When `qcmd` is unavailable, `qpos` is used as the action source.

**Swivel is column 0** of every 7-dim vector (qpos, qcmd, torques, actions). This lets the policy learn a single joint vector end-to-end instead of treating the swivel as a separate channel that must be wired up at deploy time.

### Inspecting episodes

```bash
# Rerun visualization (offline, no hardware needed)
python python/scripts/view_episode.py episodes/episode_0000.hdf5

# Save to .rrd for later viewing
python python/scripts/view_episode.py episodes/episode_0000.hdf5 --save episode.rrd
```

### Tips for good demonstrations

- **Consistency** — start and end each episode at the same pose if possible.
- **Slow, smooth motions** — jerky leader movements produce noisy actions.
- **10-30 episodes** is a reasonable starting point for simple tasks; complex tasks may need 50+.
- **Verify the camera** — check `view_episode.py` output to confirm the gripper camera captured the workspace clearly.
- **Discard bad episodes** — simply delete the `.hdf5` file before training.

---

## 3. Training

ACT (Action Chunking with Transformers) is the production training path. It
trains on the **single gripper camera** plus joint state — the scene camera is
recorded into v5 episodes but is not yet consumed by training or inference.

### Basic training

```bash
python python/training/train.py --data-dir episodes/ --output-dir checkpoints/
```

### Full argument reference

| Argument | Default | Description |
|---|---|---|
| `--data-dir` | **required** | Directory containing `episode_*.hdf5` |
| `--output-dir` | `checkpoints` | Checkpoint output directory |
| `--epochs` | 200 | Total training epochs |
| `--batch-size` | 32 | Batch size |
| `--chunk-size` | 32 | Number of future actions predicted per sample |
| `--lr` | 1e-4 | Learning rate (non-backbone) |
| `--lr-backbone` | 1e-5 | Learning rate for ResNet18 backbone (10× lower) |
| `--weight-decay` | 1e-4 | AdamW weight decay |
| `--kl-weight` | 10.0 | KL divergence weight |
| `--d-model` | 256 | Transformer hidden dimension |
| `--dim-feedforward` | 2048 | Transformer FFN dimension |
| `--z-dim` | 32 | CVAE latent dimension |
| `--nhead` | 8 | Attention heads |
| `--num-encoder-layers` | 4 | CVAE encoder layers |
| `--num-decoder-layers` | 7 | DETR decoder layers |
| `--state-mode` | `qpos_qcmd` | State layout: `qpos`, `qpos_qcmd`, `qpos_qcmd_tq` |
| `--action-mode` | `relative` | `absolute` = predict joint targets; `relative` = predict `(target − qpos)` |
| `--augment` | off | Enable train-time image augmentation (geometric crop + color jitter) |
| `--val-fraction` | 0.15 | Fraction of episodes held out for validation (0 disables) |
| `--val-seed` | 0 | Seed for train/val episode split |
| `--device` | cuda/cpu | PyTorch device |
| `--num-workers` | 4 | DataLoader workers |
| `--save-every` | 10 | Save periodic checkpoint every N epochs |
| `--resume` | off | Resume from latest periodic checkpoint in output-dir |
| `--cache` | off | Cache all episodes in RAM (faster, more memory) |
| `--no-tensorboard` | off | Disable TensorBoard logging |

### What happens during training

1. **Train/val split** — episodes are split by file (never within an episode). Validation reuses the training set's statistics so normalization is identical.
2. **Dataset init** — all episodes are discovered, a flat `(episode, timestep)` index is built, and normalization statistics (per-joint mean/std for qpos, qcmd, torques, absolute-actions, and relative-actions; per-joint min/max of absolute and relative actions for safety clamping) are computed across the full training subset. Per-episode start poses are also captured so deploy-time can pick the closest one.
3. **Each sample** — at index `(ep, t)`: load `qpos[t]`, the gripper image at `t`, and `actions[t:t+chunk_size]`. Normalize everything (z-score for positions/actions, ImageNet for the image). Build the state vector based on `state_mode`. If `--action-mode relative`, each action is converted to `(action − qpos[t])` before normalization. If `--augment`, the train image gets geometric crop + color jitter.
4. **Forward pass** — CVAE encodes `(qpos, actions)` → latent `z`, decoder predicts the action chunk from `(image, state, z)`. Loss = L1 on actions + `kl_weight × KL`.
5. **Optimizer** — AdamW with two param groups (backbone gets `lr_backbone`), gradient clipping at `max_norm=0.1`, cosine annealing to `lr × 0.01`.
6. **Checkpoints** — periodic saves every `save_every` epochs as `act_epoch_XXXX.pt`. The checkpoint with the lowest validation total-loss is additionally saved to `act_best.pt`.

### Checkpoint contents

Each `.pt` file contains everything needed for inference:

```python
{
    "epoch": int,
    "best_val": float,
    "model_state_dict": ...,
    "optimizer_state_dict": ...,
    "scheduler_state_dict": ...,
    "dataset_stats": {
        "qpos_mean", "qpos_std",              # [7] each
        "qcmd_mean", "qcmd_std",
        "torque_mean", "torque_std",
        "action_mean", "action_std",           # absolute-action stats
        "action_min", "action_max",            # absolute-action range (clamp)
        "rel_action_mean", "rel_action_std",   # delta-action stats
        "rel_action_min", "rel_action_max",    # delta-action range (clamp)
        "start_poses",                         # [N, 7] — every episode's starting qpos
        "ready_pose",                          # [7] — mean of start_poses (legacy fallback)
    },
    "config": {
        "chunk_size", "d_model", "dim_feedforward", "z_dim",
        "nhead", "num_encoder_layers", "num_decoder_layers",
        "kl_weight",
        "num_joints",     # 7 = swivel + 6 arm joints
        "state_mode",     # "qpos" | "qpos_qcmd" | "qpos_qcmd_tq"
        "state_dim",      # num_joints × (1|2|3), derived from state_mode
        "action_mode",    # "absolute" | "relative"
    },
    "train_loss": {"l1": float, "kl": float, "total": float},
    "val_loss":   {"l1": float, "kl": float, "total": float},   # null if val_fraction=0
}
```

`dataset_stats` is embedded in the checkpoint so the inference node doesn't need the original episodes.

### Resuming training

```bash
python python/training/train.py --data-dir episodes/ --output-dir checkpoints/ --resume
```

Finds the latest `act_epoch_*.pt` in the output directory and continues from `epoch + 1`. `best_val` is preserved so the best-checkpoint tracking picks up correctly.

### Training tips

- **Start with defaults** — `state_mode=qpos_qcmd`, `action_mode=relative`, `chunk_size=32`. Relative actions generalize much better on small datasets because the model only has to learn motion shapes, not absolute poses.
- **Turn on `--augment`** whenever you have fewer than ~100 episodes. Geometric crop + color jitter is cheap insurance against overfitting to lighting / framing.
- **Watch `val/total` in TensorBoard** — if it diverges from `train/total`, you're overfitting (add more episodes or augmentation). The `act_best.pt` saved at the lowest `val/total` is usually the best one to deploy.
- **`--cache`** speeds up training significantly if episodes fit in RAM.
- **Train for 200-400 epochs** for most tasks. Check `act_best.pt` with `evaluate_policy.py` before committing to longer runs.

### ACT-JEPA (experimental)

`python/training/train_jepa.py` is an experimental variant that adds a
self-supervised world-model objective on top of ACT: a predictor learns the
future gripper-image representation, regularized by SIGReg. It shares the ACT
hyperparameters above plus JEPA-specific knobs (`--future-offset`,
`--lambda-obs`, `--lambda-reg`, predictor/SIGReg sizes).

```bash
python -m python.training.train_jepa \
    --data-dir episodes/ --output-dir checkpoints/jepa \
    --augment --future-offset 32 --lambda-obs 0.5 --lambda-reg 0.05
```

Checkpoints are drop-in compatible with the plain ACT loader at inference time —
the JEPA modules are training-only, so `act_policy_node.py` and
`evaluate_policy.py` load a JEPA checkpoint unchanged. Like ACT, JEPA training
uses the gripper camera only.

---

## 4. Offline Evaluation

Before deploying on hardware, validate that the policy learned the task by replaying episodes through the model in open-loop. Evaluation uses the gripper camera (the same single-camera observation as training/inference).

### Basic usage

```bash
# Single episode
python python/scripts/evaluate_policy.py \
    --checkpoint checkpoints/act_epoch_0100.pt \
    --episode episodes/episode_0000.hdf5

# All episodes in a directory
python python/scripts/evaluate_policy.py \
    --checkpoint checkpoints/act_epoch_0100.pt \
    --episode-dir episodes/

# With temporal ensemble (matches live inference behavior)
python python/scripts/evaluate_policy.py \
    --checkpoint checkpoints/act_epoch_0100.pt \
    --episode-dir episodes/ --ensemble

# Fast mode (no camera images in Rerun)
python python/scripts/evaluate_policy.py \
    --checkpoint checkpoints/act_epoch_0100.pt \
    --episode-dir episodes/ --no-images

# Save results
python python/scripts/evaluate_policy.py \
    --checkpoint checkpoints/act_epoch_0100.pt \
    --episode-dir episodes/ --save eval.rrd --csv eval.csv
```

### All arguments

| Argument | Default | Description |
|---|---|---|
| `--checkpoint` | **required** | Path to `.pt` checkpoint |
| `--episode` | — | One or more HDF5 files (mutually exclusive with `--episode-dir`) |
| `--episode-dir` | — | Directory of `episode_*.hdf5` files |
| `--device` | cuda/cpu | PyTorch device |
| `--ensemble` | off | Enable temporal ensemble |
| `--ensemble-steps` | 16 | Past chunks for ensemble |
| `--no-images` | off | Skip camera images in Rerun |
| `--speed` | 0 | Playback speed (0 = as fast as possible) |
| `--save` | None | Save `.rrd` instead of spawning viewer |
| `--csv` | None | Export per-episode stats to CSV |

### What it does

For each frame in each episode:
1. Feeds ground-truth observations (qpos, gripper image, qcmd, torques) through the model.
2. Gets the predicted action (first action from chunk, or temporal ensemble).
3. Compares to ground-truth action via L1 error.

This is **open-loop** — ground truth observations are fed at every step, not the model's own predictions. This isolates prediction quality from compounding error.

### Rerun visualization

The viewer shows:
- **Gripper camera image** from the episode (unless `--no-images`)
- **GT vs predicted actions** overlaid per joint (amber = GT, green = predicted)
- **Per-joint L1 error** over time (red)
- **Inference time** in milliseconds

### Console output

```
Episode                                  Mean L1   Max L1   Inf (ms)
---------------------------------------- -------- -------- ----------
  episode_0000                            0.0342   0.1234       12.3
  episode_0001                            0.0298   0.0987       11.8

Joint          Mean L1   Max L1
-------------- -------- --------
swivel           0.0098   0.0312
gantry_base      0.0123   0.0456
gantry_mid       0.0234   0.0789
gantry_end       0.0189   0.0567
wrist_pitch      0.0145   0.0345
wrist_roll       0.0087   0.0234
gripper          0.0156   0.0489
OVERALL          0.0147   0.0789
```

### Interpreting results

- **Mean L1 < 0.05 rad** across all joints — good, worth trying on hardware.
- **Mean L1 0.05–0.10 rad** — mediocre, might work for coarse tasks but expect tracking errors.
- **Mean L1 > 0.10 rad** — poor, needs more training epochs or more/better demonstrations.
- **High error on specific joints** — the model may be under-constrained for that joint's motion. Check if demonstrations have enough variety for that joint.
- Compare **with and without `--ensemble`** to see if temporal smoothing improves things.

---

## 5. Deployment

The inference node subscribes to arm telemetry and the **single gripper camera**
and sends one 7-DoF `arm_joints` command per tick (swivel is joint 0).

### Dry-run first

Always test with `--dry-run` before sending commands to hardware:

```bash
python python/nodes/act_policy_node.py \
    --checkpoint checkpoints/act_best.pt \
    --dry-run
```

This runs the full inference pipeline (subscribes to telemetry + gripper camera, runs the model at 20 Hz) but does **not** send any motor commands. Verify on the console that:
- Both sources (telem, gripper cam) become ready.
- Inference time is well under 80 ms.
- Predicted positions look physically reasonable.

### Live deployment

```bash
# Default (Jetson endpoints, CUDA) — usually deploy act_best.pt
python python/nodes/act_policy_node.py \
    --checkpoint checkpoints/act_best.pt

# With a larger ensemble window
python python/nodes/act_policy_node.py \
    --checkpoint checkpoints/act_best.pt \
    --ensemble-steps 20

# CPU-only (slower, use on dev machine for testing)
python python/nodes/act_policy_node.py \
    --checkpoint checkpoints/act_best.pt \
    --device cpu

# Tighter velocity guard for both arm and swivel
python python/nodes/act_policy_node.py \
    --checkpoint checkpoints/act_best.pt \
    --max-delta 0.15 --max-delta-swivel 0.08
```

### All arguments

| Argument | Default | Description |
|---|---|---|
| `--checkpoint` | **required** | Path to `.pt` checkpoint |
| `--telem` | `tcp://localhost:5556` | ZMQ telemetry SUB endpoint |
| `--gripper-cam` | `tcp://localhost:5563` | Gripper camera SUB endpoint (single ELP UVC stream) |
| `--cmd` | `tcp://localhost:5555` | ZMQ command PUSH endpoint |
| `--device` | cuda/cpu | PyTorch device |
| `--dry-run` | off | Inference only, no commands sent |
| `--ensemble-steps` | 16 | Past chunks for ensemble (0 = disable) |
| `--max-delta` | 0.3 | Max arm-joint delta per step in rad (at 20 Hz: 0.3 = 6 rad/s) |
| `--max-delta-swivel` | 0.15 | Max swivel delta per step in rad (at 20 Hz: 0.15 = 3 rad/s) |
| `--ramp-speed` | 1.5 | Ramp speed to ready pose in rad/s |
| `--no-rerun` | off | Disable Rerun visualization |

Live controls: **SPACE** = pause/resume (holds position), **Q** = quit (press
twice to confirm; ramps to zero and disables).

### Safety features

| Feature | Details |
|---|---|
| **Source readiness** | Waits for both streams (telemetry, gripper cam) before sending any command. |
| **Closest-start ready pose** | Before inference, the node picks the training-set start pose nearest to the arm's current position and ramps to it, so the first observation is on-distribution. |
| **Staleness check** | Skips the tick if any source is > 200 ms old. |
| **Position bounds** | Absolute mode clamps actions to `[action_min, action_max]`. Relative mode clamps `(action − qpos)` to `[rel_action_min, rel_action_max]`. Both ranges come from the training data. |
| **Delta guard** | Clamps `|action − current_qpos|` per joint per step; swivel uses a tighter limit than the arm joints. |
| **Latency warning** | Warns if inference takes > 80 ms (motor watchdog is 100 ms). |

### Command dispatch

The policy outputs a 7-dim action each tick and sends it as a single
`arm_joints` command (swivel is joint 0 of the unified arm). The model learns
whole-body coordination across all 7 joints in one vector.

### Important warnings

- **Do NOT run `teleop.py` and `act_policy_node.py` simultaneously.** Both push to `:5555`. Interleaved commands are dangerous.
- **`state_mode` / `action_mode` must match training.** The checkpoint carries these in `config` and the node uses them automatically. For old checkpoints without these fields, the node falls back to `state_mode=qpos_qcmd`, `action_mode=absolute`.
- **Arm gains** are loaded from `config/teleop.yaml` (the `arm.kp` / `arm.kd` values; older split `gantry.*` + `drive.swivel_*` layouts are stitched into a swivel-first 7-element vector). Make sure these match what was used during data collection.

---

## 6. Episode Replay (without the model)

For debugging or verifying episodes, you can replay a recorded episode directly on hardware (sending the recorded commands without any model):

```bash
# Live replay (moves to the start pose first by default)
python python/scripts/episode_replay_live.py episodes/episode_0000.hdf5

# Dry-run (no commands sent)
python python/scripts/episode_replay_live.py episodes/episode_0000.hdf5 --dry-run

# Skip the goto-start ramp
python python/scripts/episode_replay_live.py episodes/episode_0000.hdf5 --no-goto-start

# Loop indefinitely
python python/scripts/episode_replay_live.py episodes/episode_0000.hdf5 --loop

# Half speed
python python/scripts/episode_replay_live.py episodes/episode_0000.hdf5 --speed 0.5
```

Controls: SPACE/P = play/pause/resume, R = restart, X = abort + shutdown, Q = quit.

The replay prefers `observations/qcmd` (commanded positions) over `observations/qpos` (actual positions) when available, since commanded positions avoid gravity sag.

---

## Typical Workflow

```
# 1. One-time: calibrate the leader arm
python python/scripts/so101_calibrate.py --port COM4

# 2. Collect 20 demonstrations of the task (auto-detect leader / rover / scene cam)
python python/scripts/collect_demo.py --gui --output-dir episodes/pick_cup

# 3. Inspect a few episodes visually
python python/scripts/view_episode.py episodes/pick_cup/episode_0005.hdf5

# 4. Train for 300 epochs with augmentation + 15% validation
python python/training/train.py \
    --data-dir episodes/pick_cup \
    --output-dir checkpoints/pick_cup \
    --epochs 300 --augment --val-fraction 0.15

# 5. Evaluate the best-val checkpoint offline
python python/scripts/evaluate_policy.py \
    --checkpoint checkpoints/pick_cup/act_best.pt \
    --episode-dir episodes/pick_cup \
    --ensemble --csv eval_pick_cup.csv

# 6. If Mean L1 looks good, dry-run on hardware
python python/nodes/act_policy_node.py \
    --checkpoint checkpoints/pick_cup/act_best.pt \
    --dry-run

# 7. Deploy live
python python/nodes/act_policy_node.py \
    --checkpoint checkpoints/pick_cup/act_best.pt
```

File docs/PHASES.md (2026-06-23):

# AIZEE Software Stack - Implementation Phases

Implementation roadmap and status. The early phases are complete and deployed;
status markers reflect the current system. See the README for the live
subsystem snapshot.

Legend: ✅ done · ◐ partial / optional · ◻️ future

---

## Phase 0: Project Foundation ✅

**Goal:** Establish repository structure, tooling, and development environment

### Tasks:
1. **Repository setup** ✅
   - Git repo with directory structure
   - LICENSE file (MIT)
   - README with project vision, hardware specs

2. **Development environment** ✅
   - Jetson Orin Nano setup: JetPack 6.x, Rust toolchain, Python 3.10+
   - Dev / operator machine: Rerun viewer, ZeroMQ, leader drivers, training stack

3. **Core dependencies** ✅
   - Rust: `tokio` (async), `zmq`, `socketcan` / `gs_usb` (CAN interface), `pyo3` (reserved)
   - Python: `pyzmq`, `rerun-sdk`, `numpy`, `torch`, `h5py`, `pyrealsense2`

4. **Hardware parameter config** ✅
   - `config/hardware_jetson_rover.yaml` (rover) + camera configs
     (`hardware_jetson_gripper_cam.yaml`, `hardware_jetson_scene_cam.yaml`)

**Deliverable:** Clean repo, hardware talking to dev machine, config files defining the system.

---

## Phase 1: Rust Motor Control Core ✅

**Goal:** Low-level CAN interface with ROBSTRIDE motors, deterministic control loop

### Tasks:
1. **CAN communication library** ✅
   - ROBSTRIDE protocol in Rust: `enable_motor()`, `set_position()`, `set_velocity()`, `read_state()`
   - Multi-motor single CAN bus (`can1`, gs_usb adapter)
   - Error handling: CAN timeouts, motor faults, fault recovery

2. **Motor controller node** ✅
   - Control loops: **400 Hz** arm (CAN-bus limited), **100 Hz** base (wheels + swivel)
   - `tokio` for async I/O with a deterministic control loop
   - State machine: IDLE → ENABLED → RUNNING → ERROR

3. **ZeroMQ command interface** ✅
   - Subscribe to commands on `tcp://*:5555` (JSON/msgpack)
   - Message types: `drive`, `arm_joints` (7-DoF, swivel-first), `bundle`, `enable`/`disable`, `emergency_stop`

4. **Telemetry publishing** ✅
   - Motor states on `tcp://*:5556` at **50 Hz** (position/velocity/torque/temperature)

5. **Safety features** ✅
   - Watchdog: holds position if no command for ~500 ms
   - Soft limits for arm joints (from config)
   - Emergency-stop path (wireless ESP-NOW e-stop bridged to ZMQ)

**Deliverable:** `motor_control` Rust binary on the Jetson, controllable via ZeroMQ, publishing telemetry. ✅

---

## Phase 2: Python Teleop Interface ✅

**Goal:** Human-in-the-loop control

### Tasks:
1. **Input handlers** ✅
   - Leader arms: **SO-101** (Feetech STS3215), **OpenRB-150 + Dynamixel XL330**, **Quest VR** (WebXR)
   - Gamepad + keyboard (WASD drive); M5Stack Joystick2 on the OpenRB leader
   - Per-leader calibration (`config/so101_calibration.json`, `openrb_calibration.json`, `robstride_calibration.json`)

2. **Command publisher** ✅
   - Connects to the Jetson over ZeroMQ; rover IP auto-resolves across networks
   - Dedicated cmd-sender thread re-emits the latest bundle at ~100 Hz

3. **GUI control panel** ✅
   - PySide6 panel (`--gui`) embedding the Rerun web viewer
   - Live motor state, camera preview, V4L2 camera controls, runtime leader hot-plug

4. **Configuration loader** ✅
   - `config/teleop.yaml` for input mappings, scaling, gains, and network endpoints

**Deliverable:** `teleop.py` + leader drivers, controlling the robot interactively. ✅

---

## Phase 3: Camera Nodes ✅

**Goal:** Stream camera data to the policy/recorder pipeline

> **Note:** the original plan streamed RealSense data from separate Raspberry
> Pi 4 nodes over PoE. That split has been retired — **both cameras now run on
> the Jetson**.

### Tasks:
1. **Gripper camera** ✅
   - ELP-USBFHD01M-L21 USB UVC, color **1024×768 @ 30 fps** (MJPG)
   - Primary close-up training observation; PUB on `tcp://*:5563`, V4L2 control REP on `:5573`

2. **Scene camera (optional)** ◐
   - Intel RealSense D435/D435i/D455, color + depth **640×480 @ 15 fps**
   - Externally mounted wider workspace view with depth; PUB on `tcp://*:5564`
   - Auto-detected at runtime: present ⇒ recorded (static mode), absent ⇒ rover mode

3. **Resilience & services** ✅
   - Auto-start via udev + systemd (`aizee-gripper-cam`, `aizee-scene-cam`)
   - Reinit on disconnect

**Deliverable:** Camera nodes on the Jetson, streaming over ZeroMQ. ✅

---

## Phase 4: Rerun Integration ✅

**Goal:** Visualize all data streams in real time + log

### Tasks:
1. **Live visualization** ✅
   - Rerun used across teleop, collection, evaluation, and inference
   - Motor telemetry, camera images, joint/leader scalars

2. **URDF visualization** ✅
   - URDF exported from OnShape, rendered with joint angles from telemetry (GUI / preview)

3. **Logging & playback** ✅
   - `.rrd` export from `view_episode.py` / `evaluate_policy.py`; offline replay in the viewer

**Deliverable:** Live visualization + logging working. ✅

---

## Phase 5: System Integration & Monitoring ✅

**Goal:** Robust multi-node system with health monitoring

### Tasks:
1. **Launch / services** ✅
   - On-robot subsystems run as systemd services and start on boot
   - Deploy scripts under `scripts/` (`deploy_jetson_rover.sh`, `deploy_gripper_camera.sh`, `deploy_scene_cam.sh`, `deploy_heartbeat.sh`)

2. **Health monitoring** ✅
   - **Heartbeat dashboard** at `http://<jetson>:8088` — service status, recent logs, host metrics, live telemetry
   - Tufty2040 on-robot status display

3. **Networking** ✅
   - Three reach paths probed in priority order: `192.168.0.27` (LAN/WiFi) → `10.42.0.1` (USB-C ethernet) → `192.168.50.1` (robot's own **WiFi AP**, autoconnects on boot)

4. **Error recovery** ✅
   - CAN fault recovery in the Rust core; camera reinit on disconnect; safe-stop on stale commands

**Deliverable:** Reliable, monitored system. ✅

---

## Phase 6: Imitation Learning Pipeline ✅

**Goal:** Collect demonstrations and train/deploy policies

### Tasks:
1. **Demonstration collection** ✅
   - `collect_demo.py --gui` — leader, rover IP, and scene cam auto-detected
   - HDF5 episodes: **v4** (gripper cam + 7-DoF joint states/commands/torques + timestamps), **v5** (v4 + scene cam) when the scene cam is present
   - Camera/telemetry timestamp sync; 20 Hz recording

2. **ACT training** ✅
   - `train.py` — Action Chunking with Transformers (CVAE + DETR decoder, ResNet18 backbone)
   - Gripper-camera observation + 7-DoF state; relative/absolute action modes; train/val split; checkpoints with embedded dataset stats

3. **ACT-JEPA training** ◐ *(experimental)*
   - `train_jepa.py` — adds a self-supervised world-model objective (future-image prediction + SIGReg)
   - Inference-compatible with the ACT checkpoint loader

4. **Offline evaluation** ✅
   - `evaluate_policy.py` — open-loop replay through the model, per-joint L1, optional temporal ensemble

5. **Live inference** ✅
   - `act_policy_node.py` — 20 Hz, single gripper camera, safety clamps + closest-start ready pose
   - `episode_replay_live.py` — replay recorded commands on hardware (no model)

> **Multi-camera training/inference is a follow-up.** The scene cam is recorded
> into v5 episodes, but `train.py`, `train_jepa.py`, `evaluate_policy.py`, and
> `act_policy_node.py` currently consume the gripper camera only.

**Deliverable:** End-to-end collect → train → evaluate → deploy pipeline. ✅
See [LEARNING_PIPELINE.md](LEARNING_PIPELINE.md).

---

## Future Work

- ◻️ **Multi-camera policies** — consume the recorded scene camera (RGB-D) in training and inference.
- ◻️ **LiDAR integration** — 2× SLAMTEC RPLiDAR A1M8 driver exists (`rust/lidar_control`) but is not enabled in all configurations; sensor fusion / mapping is future.
- ◻️ **Autonomous behaviors** — navigation / obstacle avoidance on the rover.
- ◻️ **PyO3 bindings** — promote hot Python paths into the Rust core if profiling warrants.
- ◻️ **Task-conditioned / multi-task policies** — beyond single-task ACT checkpoints.

---

## Status Summary

| Phase | Status |
|---|---|
| 0: Foundation | ✅ |
| 1: Rust motor control (400 Hz arm / 100 Hz base, fault recovery) | ✅ |
| 2: Teleop (SO-101 / OpenRB-150 / Quest VR, GUI) | ✅ |
| 3: Cameras on the Jetson (gripper + optional scene) | ✅ |
| 4: Rerun visualization + logging | ✅ |
| 5: Integration, heartbeat dashboard, WiFi AP | ✅ |
| 6: Imitation learning (ACT done, ACT-JEPA experimental) | ✅ / ◐ |
| Future: multi-camera, LiDAR fusion, autonomy | ◻️ |

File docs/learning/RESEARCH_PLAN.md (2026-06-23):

# AIZEE Learning Pipeline — Research & Execution Plan (V2)

Status: **Draft, learning-dev branch**, 2026-04-30
Author: Claude (revising user-supplied plan after literature review)
Scope: forward-looking research plan for the AIZEE manipulator's learning stack.

This document supersedes the architectural sections of an earlier draft titled "Embodied Foundation Model: Full-Stack Research & Execution Plan." That draft assumed a wearable-data-collection greenfield project styled after Generalist AI's GEN-1 / Physical Intelligence's pi0 / Sunday Robotics' ACT-1. **AIZEE is none of those things**: it is a single mobile manipulator with a working ACT pipeline, ~40 teleoperated demonstrations, and a single-GPU training budget. The original plan also rested on a false architectural unification of those three systems — see [§1.3](#13-what-the-original-plan-got-wrong). This V2 plan is sized for the project we have.

The companion document [LEARNING_PIPELINE.md](../LEARNING_PIPELINE.md) is the operational guide ("how to run training and deployment today"). This document is "where we are going next."

---

## 1. Where we are

### 1.1 Current baseline (production)

- **Robot:** AIZEE mobile manipulator. 7-DOF effective control: `swivel + gantry_base + gantry_mid + gantry_end + wrist_pitch + wrist_roll + gripper`. Base wheels separate (100 Hz loop). Arm joints at 400 Hz (CAN-bus limited).
- **Sensing:** 1× ELP UVC gripper camera + 1× Intel RealSense scene camera (USB to Jetson, RGB used for policy; scene cam also provides depth). The stereo D435 wrist pair and the 4× D455 PoE rover cameras have been retired. Motor torques available.
- **Demos:** Teleoperation via SO-101 leader arm or OpenRB-150 + Dynamixel XL330 leader. Recorded as HDF5 at 20 Hz with `qpos`, `qcmd`, `torques`, `images/{gripper,scene}`. ~40 episodes on disk today.
- **Policy:** ACT (Zhao et al., 2023). ResNet18 (FrozenBN, ImageNet-pretrained) + DETR-style transformer decoder + CVAE prior. `chunk_size=32`, `d_model=256`, `z_dim=32`. Trained with L1 + KL. ~30–50M params.
- **Inference:** [act_policy_node.py](../../python/nodes/act_policy_node.py) runs at 20 Hz on Jetson with temporal ensemble over the last 16 chunks. Latency budget < 80 ms (motor watchdog is 100 ms).
- **Action space:** 7-DOF joint positions, mode `absolute` or `relative` (`relative` recommended for small datasets — model learns motion shapes rather than absolute poses).
- **Safety:** position bounds, per-step delta clamps (tighter on swivel), source-readiness gating, latency warnings.

### 1.2 What the user-supplied plan assumed that doesn't apply

| Plan assumption | AIZEE reality |
|---|---|
| Wearable handheld gripper for data collection (UMI lineage) | We use teleop on the actual robot. No SLAM pipeline, no fisheye undistortion, no operator scaling to 500k hours. |
| Cross-embodiment transfer is the goal | One specific robot; one specific gripper. No transfer needed. |
| Action space is 8-D end-effector deltas + gripper width + force | Action space is 7-D joint positions. EE-relative is **possible** but requires a fast IK on the gantry chain — that's a project, not free. |
| 7B-parameter model trained from scratch on 500k hours | Single GPU; ~40 episodes; ~20k frames total. Training a 7B model from scratch needs ~50–100k H100-hours and ~1B+ frames. Off by ~3 orders of magnitude. |
| Force/contact sensing on fingertips | We have motor torques (gripper motor current/torque). Useful proxy, not a tactile array. |
| ImageNet pretraining is harmful, train ViT from scratch | At our data scale, ImageNet pretraining is **strictly helpful**. The ACT recipe already uses it. The "train ViT from scratch" advice is conditional on having Generalist-scale data. |
| 30 Hz control with 80 forward passes per cycle (Harmonic Reasoning) | 20 Hz ACT inference today. 80 forward passes of even a 50M-param model on Jetson Orin Nano in 25 ms is unrealistic without heavy quantization and custom kernels. |

### 1.3 What the original plan got wrong

I asked a research agent to fact-check the plan's central claim — that "energy-based implicit transformer with harmonic trajectory optimization" is the convergent architecture of GEN-1, pi0, and ACT-1. **It isn't.** Findings, briefly:

1. **pi0 is flow matching**, explicitly. arXiv 2410.24164 (Black et al., Oct 2024) is literally titled "pi0: A Vision-Language-Action Flow Model for General Robot Control." pi0.5 (arXiv 2504.16054, Apr 2025) is the same flow-matching backbone with co-training on heterogeneous data. Weights are open at `Physical-Intelligence/openpi`. Calling it "energy-based implicit" is wrong.
2. **GEN-1's "Harmonic Reasoning" is real, but is not a Fourier basis or trajectory optimization technique.** Generalist describes it as an **asynchronous continuous-time perception/action interleaving** that removes the System-1/System-2 split — the model "thinks and acts" simultaneously. There is no public claim it is energy-based. There is no arXiv paper for GEN-0 or GEN-1; only blog posts. Architectural specifics (param count, loss, exact attention pattern) are undisclosed.
3. **Sunday Robotics' ACT-1 is unpublished.** The system is real, the company is real (Tony Zhao + Cheng Chi, ~$1.15B valuation), and they advertise "ACT-1 foundation model" in PR. But there is no paper. Founders' history (ACT, Diffusion Policy) makes a diffusion-style head a reasonable inductive guess, not a known fact. (Note: not to be confused with Adept's ACT-1 web-browser agent — different system, different company.)
4. **Implicit BC + InfoNCE doesn't scale to action dim > ~5–7.** Florence et al. 2021 showed strong results on small-action-dim tasks. Diffusion Policy (Chi, RSS 2023) explicitly outperforms IBC across their benchmarks. By 2026, IBC is not the competitive default. Our action dim is 7 — right at the IBC failure boundary.
5. **Harmonic / Fourier-basis action chunks exist in the literature** (Fourier Flow Matching, FCNet, classical DMPs/ProMPs/ProDMPs) but are a small niche, **not** what GEN-1, pi0, or ACT-1 use.

This V2 plan keeps the parts of the original that are useful (action chunking, receding horizon execution, conservative offline RL post-training, the harmonic basis as an *optional* smoothness regularizer) and replaces the load-bearing claims with documented, scale-appropriate techniques.

---

## 2. Goals

User decisions (2026-04-30) shape the plan: primary goal is **robust task performance**, V1 evaluation is **one narrow well-scoped task**, demo collection cadence is **fast (200+ demos in 1–2 days)**, and the kept research arms are **harmonic basis, EE-space + IK adapter, and RL post-training**. A third overhead camera is explicitly out of scope (precedent: Generalist's deployments work without one — wrist-mounted cameras carry the workload).

### 2.1 Primary goal (V1: ~6 weeks)

Replace the ACT (CVAE + L1) head with a **Diffusion Policy** head, on a fresh **single-task ~200-episode dataset** collected in parallel with the implementation. Demonstrate ≥ ACT performance on that task and meaningfully better behavior on at least one of: out-of-distribution starts, multi-modal action distributions, or recovery from perturbations. This is the same upgrade path ALOHA Unleashed (CoRL 2024) took.

The 200-demo scale is comfortably in Diffusion Policy's documented strong regime — well above the ~40 we have today, well below ALOHA Unleashed's 26k. With one well-scoped task, this is the highest-probability path to a working autonomous demo.

### 2.2 Secondary goals (V2: pick after V1 lands, ~weeks 7–12)

V2 picks from the research arms below based on V1 results. The kept arms (in expected priority order, to revisit when V1 finishes):

1. **RL post-training** — Cal-QL or RLPD on top of V1 to push beyond demonstration speed and improve perturbation recovery on the chosen task.
2. **Harmonic / Fourier action-chunk parameterization** — as a smoothness regularizer on the V1 diffusion head. Cheap ablation, ~1 week.
3. **EE-space actions + IK adapter** — build URDF-based fast IK on the gantry chain so the policy can output end-effector deltas. Required if VLA fine-tuning is ever attempted; also useful for cleaner action-space comparisons.

VLA fine-tuning (OpenVLA-OFT, pi0 via openpi) is **demoted to optional research**, not a planned V2 path. The user's priority on robust task performance + the demo-cadence answer (we can collect data, we don't need pretrained semantics) makes the cost/benefit unfavorable. Keep the EE/IK arm warm in case this changes.

### 2.3 Cheap wins to do alongside V1

- Add motor-torque and gripper-width as explicit policy inputs (`state_mode=qpos_qcmd_tq`). Already in HDF5; one-line training flag. The gripper torque is a contact-pressure proxy that may be load-bearing for grasp tasks.

### 2.4 Explicit non-goals

- A wearable data-collection device. We have a robot; we use it.
- A 7B foundation model trained from scratch.
- "Cross-embodiment transfer" — we have one robot.
- Energy-based BC with InfoNCE. Documented to fail at our action dim.
- Custom paged attention / int4 quantization / inference-time optimization with 80 forward passes per cycle. Out of budget for a 1–2 person project on a single Jetson.
- A third overhead camera. Generalist's published demos do not require one; wrist-mounted cameras suffice. We keep the bandwidth budget for V2 research arms instead.
- VLA fine-tuning (OpenVLA-OFT, pi0) as a primary V2 path. Reconsider if V1 plateaus and we can't close the gap with data + RL.

---

## 3. V1 — Diffusion Policy upgrade

### 3.0 Step 0 — Pick the task and collect 200 demos (parallel with implementation)

The user's answer locks two things: V1 evaluates on **one well-scoped task**, and we can collect **~200 demos in 1–2 focused sessions**. This step happens in parallel with the implementation work in §3.2–§3.6 — the diffusion head doesn't need the new data to be written and unit-tested.

Task-selection criteria (pick one):
- **Bounded workspace**: the entire interaction fits comfortably in the visible region of both wrist cameras.
- **One nominal strategy** but with **multi-modal demonstration freedom**: e.g. "pick up the cup and place it in the bin" — the human can grasp from multiple angles, but success is binary. Multi-modality is exactly where Diffusion Policy beats ACT, so the task should permit it. A task with one rigid optimal trajectory is a worse showcase.
- **Cheap reset**: we will run 20+ trials per evaluation; manual reset of a cluttered scene burns hours.
- **Mechanically benign**: nothing fragile, nothing that punishes a 6-rad/s overshoot. We are still tuning safety margins.
- **Recordable failure modes**: we want to be able to label success/failure clearly from the camera stream (helpful for any future RL reward).

Strong default candidate: **single-object pick-and-place on a marked target**. Specific cup or block, marked target zone on the table, reset = put the object back at one of N starting positions. This task hits all five criteria, gives multi-modality (multiple grasp poses) without being chaotic, and is the same task family ACT/Diffusion comparisons are typically published on, which makes our result interpretable against the literature.

Collection protocol (1–2 days):
- Use [collect_demo.py](../../python/scripts/collect_demo.py) on the SO-101 (or OpenRB-150) leader.
- Vary object starting position across a defined grid (e.g. 5×5 grid on a marked region, ~8 demos per cell). Distractor objects optional in V1 — add them later if generalization plateaus.
- Vary lighting and incidental scene changes naturally, but keep the **target zone, table surface, and gripper unchanged** during collection.
- Save into a dedicated `episodes/{task_name}/` directory so we can train independently of the existing mixed `episodes/` set.
- Spot-check every ~25 demos with [view_episode.py](../../python/scripts/view_episode.py) — one bad calibration drift can poison the dataset.
- Quality target: ≥95% of recorded episodes pass a manual review for "the task was actually completed." Discard the rest before training.

Once the new dataset is on disk, the existing 38 mixed episodes become a useful **ACT-baseline-vs-Diffusion-baseline** comparison set for the offline evaluation in §3.7 — they cover broader behavior and let us check that V1 hasn't simply overfit to the new task.

### 3.1 Why diffusion first

For ~200 demonstrations on a single robot and a single narrow task, Diffusion Policy is the documented practical default in 2026. Reasons:
- Strong at this data scale — robust at small data (recent analysis suggests it largely "memorizes a latent action lookup table" and is OOD-robust whenever a near-neighbor observation exists in training), and improves cleanly with more demos. 200 demos on one task is squarely in its strong regime.
- Stable training, well-supported tooling (LeRobot has a reference implementation), apples-to-apples comparable to our existing ACT.
- Lowest delta from current code: same vision backbone, same chunk size, same control loop. The change is local to [act_model.py](../../python/training/act_model.py), [train.py](../../python/training/train.py), and the action-sampling code in the inference node.
- Documented success on the same upgrade path: ALOHA Unleashed (CoRL 2024) is exactly this — ACT (CVAE+L1) → Diffusion Policy transformer head, on broadly similar hardware.

Flow matching (pi0-style) is ~equivalent in quality with simpler objective and faster inference, but the openpi stack is heavier and the win over diffusion at our scale is small. Not part of this plan.

### 3.2 Architecture

Keep:
- ResNet18 (FrozenBN, ImageNet-pretrained) image encoder, shared across left/right cameras. *Verify by ablation* whether `pretrained=True` still wins at the ~40-episode scale; current ACT defaults say yes.
- State encoder MLP (2 layers, `state_dim → d_model`) for `[qpos, qcmd]` (and optionally torques — see §3.6).
- Concatenated context tokens: `[img_left_tokens, img_right_tokens, state_token]`. ~80 spatial tokens per camera at 240×320 input.

Replace:
- The CVAE encoder + DETR decoder + L1 action head, with a **conditional diffusion head** that denoises a chunk of `chunk_size × num_joints` actions.

Two reasonable diffusion variants — choose one and ablate the other after V1 lands:

**Variant A — CNN-based 1D diffusion (Chi et al. RSS 2023, "Diffusion Policy"):**
- 1D U-Net over the action-chunk time axis, FiLM-conditioned on the encoded observation token sequence (pooled or via cross-attention adapter).
- Standard DDPM/DDIM noise schedule. Default 100 training steps, 16 inference DDIM steps. Tune inference steps for 20 Hz budget.
- Pros: simpler, faster to train, fewer params (~10–20M for the diffusion head).
- Cons: no transformer cross-attention to per-token observations — has to compress observations into a global conditioning vector or a small set of tokens.

**Variant B — Transformer diffusion (ALOHA Unleashed / "Diffusion Policy Transformer"):**
- Transformer decoder over learned action-chunk queries (one per timestep, like our current ACT decoder). Cross-attends to context tokens. Predicts noise.
- Pros: cleanly replaces our existing DETR decoder; preserves per-token observation conditioning.
- Cons: slightly more params, slower per step.

**Recommendation: start with Variant B.** The change to our codebase is minimal — replace `ACTDecoder.forward` to also accept a `(noisy_action_chunk, timestep_emb)` and predict noise instead of clean actions. The existing chunk-size = 32 query embedding becomes a noisy-action-chunk projection. This is a single-file change to [act_model.py](../../python/training/act_model.py).

### 3.3 Loss

- L2 (or L1) on predicted noise vs. true noise. Keep weighting simple — no KL term, no auxiliary losses in V1.
- (Optional) Action range clamp at sample time, matching what `act_policy_node` already does. Useful for safety; doesn't change training.

### 3.4 Sampling at inference

DDIM with K steps (K=8–16 to start). Each step is one transformer forward pass. Budget at 20 Hz: 50 ms total per cycle, ~30 ms for inference (current ACT uses ~12 ms on Jetson). With K=16 steps and the same backbone, expect ~16× the per-cycle inference time of ACT — back-of-envelope ~190 ms, **over budget**.

Mitigations, in order of preference:
1. K=8 or fewer DDIM steps. Diffusion Policy reports usable performance at K=10; flow-matching variants work at K=4. Test reconstruction error vs. K offline before deploying.
2. **Action-chunk receding horizon** is already in place — we execute the first M=5–8 of the 32-step chunk and only re-plan once per chunk-step. This means we run inference once per ~250 ms (4 Hz), not per 50 ms. 16 DDIM steps in 250 ms is plausible.
3. Distill to a 1-step student (consistency model / shortcut model) once V1 is working. Defer; this is a follow-up, not blocking.
4. Quantize to int8 (TensorRT). Defer.

Concretely, for V1 we should **reduce inference-call frequency**, not chase 20 Hz model invocations. Current ACT essentially also does this (chunk_size=32 with ensemble window 16 means model is called every step but the ensemble smooths). Diffusion Policy's published recipe calls the model once per ~8–16 control steps and executes the predicted chunk open-loop until the next call.

### 3.5 Training

Re-use [train.py](../../python/training/train.py)'s harness — episode iteration, normalization stats, train/val split, augmentation toggle, checkpointing, TensorBoard. Replace the inner forward call. Keep:
- AdamW, separate LR for backbone (1e-5) vs head (1e-4)
- Cosine annealing
- Gradient clip 0.1 (this is unusually tight; verify it doesn't choke diffusion training — diffusion typically uses 1.0)
- Per-joint normalization stats from `dataset_stats`
- Augmentation: geometric crop + per-camera color jitter (already implemented; should use it always at our data scale)

Hyperparameter sweep (small, 4–8 runs):
- Diffusion steps: {50, 100} train / {8, 16} inference
- Action mode: {`absolute`, `relative`}; expect `relative` to win (matches current ACT finding)
- Backbone unfreeze epoch: {0, 20} (warm up the head before unlocking the vision backbone)
- Optional: `pretrained_encoder` {True, False}

### 3.6 Wider state vector (cheap win, do alongside V1)

The HDF5 already stores `qpos`, `qcmd`, `torques` per timestep. The current `state_mode=qpos_qcmd` ignores torques. Try `state_mode=qpos_qcmd_tq` — the gripper motor's torque is a contact-pressure proxy that may be load-bearing for grasp tasks. This is a one-line training flag and a checkpoint config change.

### 3.7 Evaluation

Re-use the existing offline harness in [evaluate_policy.py](../../python/scripts/evaluate_policy.py): open-loop replay through the model, per-joint L1 vs. ground truth, with and without temporal ensemble. Acceptance gate before deploying live:
- Mean L1 ≤ ACT baseline within 10%, on held-out validation episodes.
- Mean L1 ≤ 0.05 rad across all joints.
- Inference latency ≤ chunk-step budget (≤ 250 ms per chunk re-plan at chunk_step=8, 20 Hz).

Then dry-run on hardware (`--dry-run` in `act_policy_node.py`), then live with conservative `--max-delta` (start at 0.15 rad/step, half of training-time clamp). Compare:
- Success rate on the same 20 trials per task
- Cycle time
- Smoothness (RMS jerk, third derivative of `qpos`)
- Recovery from one specific perturbation (e.g., experimenter slides the target object 5 cm mid-task)

### 3.8 Codebase changes for V1

Concrete file-level diff:

| File | Change |
|---|---|
| [python/training/act_model.py](../../python/training/act_model.py) | Add `DiffusionPolicy` class alongside `ACTPolicy`. Re-uses `ImageEncoder`, `StateEncoder`. Replaces `CVAEEncoder` and the L1 action head. Add a small timestep-embedding MLP. |
| [python/training/train.py](../../python/training/train.py) | Add `--policy {act,diffusion}` flag. For diffusion: sample timestep, add noise to action chunk, predict noise, MSE loss. No KL term. |
| [python/training/dataset.py](../../python/training/dataset.py) | No change — the (state, images, action_chunk) tuple is the same. |
| [python/nodes/act_policy_node.py](../../python/nodes/act_policy_node.py) | Add diffusion-sampling path; bump default chunk-step from 1 to 8 (re-plan less often). Keep all safety clamps. |
| [python/scripts/evaluate_policy.py](../../python/scripts/evaluate_policy.py) | Detect policy type from checkpoint config and dispatch. |
| docs/LEARNING_PIPELINE.md | After V1 ships, add a "Diffusion Policy" section parallel to the existing ACT section. |

The checkpoint format already has a `config` dict — add a `policy_type` field and version-bump `format_version` so old ACT checkpoints still load.

---

## 4. V2 — pick a research arm after V1 lands

V2 is decided on V1 results. The shortlist (per user's stretch-arm picks): RL post-training, harmonic action-chunk parameterization, EE-space + IK adapter. Each addresses a different V1 failure mode, so the V1 result tells us which to start.

| If V1 result is… | Pick this arm | Reasoning |
|---|---|---|
| Diffusion beats ACT cleanly but is jerky / smoothness-limited | **Harmonic basis (§5.1)** | Cheap (~1 week), directly targets jerk by construction. No new data needed. |
| Diffusion is at parity with ACT in success but slow / brittle to perturbations | **RL post-training (§5.2)** | Speed bonus + perturbation recovery are exactly what RL post-training delivers when imitation has plateaued. |
| Diffusion gives clean comparison but joint-space limits transfer / scope of future work | **EE-space + IK adapter (§5.3)** | One-time engineering investment; opens the door to clean comparisons against EE-space policies and to future VLA fine-tuning if priorities change. |
| Diffusion fails to materially improve over ACT | Re-collect with more multi-modality / more environmental variation, then re-evaluate. Don't add a research arm yet — fix the data first. | If V1 doesn't beat ACT, it's almost always the data, not the architecture. |

The arms are described in §5. The expected default, absent surprises, is to attempt **harmonic basis first** (cheap, low-risk, fast feedback) and **RL post-training second** (the higher-impact arm, but costlier and riskier).

---

## 5. Research arms (V2 candidates)

### 5.1 Harmonic / Fourier action-chunk parameterization

Represent each `chunk_size × 7` action chunk as a truncated Fourier series rather than raw timestep values. For chunk size 32 and K=10 harmonics, this is 7 × (1 + 2K) = 147 coefficients, vs. 32 × 7 = 224 raw values. The point is not compression — it's:
- **Smoothness by construction.** Low-K representations cannot produce jerky motion.
- **Time-axis rescaling.** Execute the same coefficients at variable speed without re-planning.

This is **Fourier Flow Matching** territory (Liu et al., NeurIPS 2024) and the classical **ProDMP** lineage. It is **not** what frontier labs (GEN-1, pi0, ACT-1) use, as far as anyone has published — so this is genuine research, not best-practice imitation. That cuts both ways: real upside if it works, no template to copy.

Experiment design (~1 week on top of V1):
1. Build a fixed orthogonal Fourier basis matrix `Φ` (shape `[chunk_size, 1+2K]`) and its left-inverse `Φ⁺`.
2. During training: project ground-truth action chunks to coefficients (`c = Φ⁺ a`), train the diffusion head to denoise in coefficient space, decode back via `a = Φ c`. Loss is still MSE on noise — just in coefficient space.
3. Sweep K ∈ {5, 10, 20}. K=10 is likely too low for sharp grasp actions (gripper close is high-frequency); a per-joint K (e.g. K=20 on the gripper, K=10 elsewhere) is worth trying if a uniform K creates a clear gripper-failure signature.
4. Compare to the V1 (raw-action) baseline on:
   - Success rate (must not regress)
   - RMS jerk (third derivative of `qpos`) — the metric this arm is designed to improve
   - Cycle time (should at least not get worse)
   - Optional: time-axis rescaling — execute the same coefficients at 0.7× and 1.3× speed, see whether success rate degrades gracefully.

Risk: K too low may kill the gripper's fast close. Risk mitigation: per-joint K or skip the harmonic projection on the gripper channel entirely — the basis change is per-dimension, so this is trivial.

### 5.2 Conservative offline-to-online RL post-training

The honest 2026 read on Cal-QL: it works in benchmarks but real-robot adoption is limited and there are documented failure modes (initial performance drop online, struggles when offline data isn't retained during fine-tuning). **RLPD-style hybrid online RL** (use offline demos as part of the online replay buffer at every gradient step) is a more robust real-robot recipe and has been demonstrated on real manipulators in 2024–2025 papers.

Recommended formulation if we attempt this:
- **Reward**: sparse binary task-success (auto-detected from camera or simple geometric check on the target zone), augmented by a small smoothness penalty (jerk) and a hard penalty on torque spikes.
- **Speed bonus**: a small reward on `1/completion_time` to push beyond demonstration speed. Tune carefully — this is the lever that produces "GEN-1-style 3× speedup" results, but it's also the lever that produces hardware-damaging velocity-maxing if mis-weighted.
- **KL penalty** to the V1 Diffusion Policy action distribution to keep behavior close to the imitation baseline (the same regularizer used in RLHF for language models). This is the single most important guardrail — without it, online RL can rapidly depart from anything we trained for.
- **Replay buffer** seeded with the 200 demonstrations from V1, re-sampled at every gradient step (RLPD recipe).

What we need to build before starting:
1. **Auto-reset.** A reliable reset behavior that returns the workspace to a known starting condition without human intervention. For pick-and-place this is "robot places the object back at a sampled grid cell." This is its own subproject — possibly the largest engineering item in V2.5.
2. **Success detector.** Camera-based geometric check (object in target zone) is fastest. Add a torque-spike detector for failed grasps.
3. **Hard safety envelope.** Workspace box, joint-limit buffers, max torque per joint, max velocity per joint. Implemented in the Rust motor-control layer, not the Python policy. Already partially in place; needs an explicit RL-mode tightening.
4. **Breakage budget.** Even with the envelope, expect some hardware wear — gripper rubber, cables, motor brushes. Don't run RL on the only working motor of a given type without spares on hand.

Expected runtime: **at least 1–2 weeks of robot-time** for a meaningful comparison vs. V1, assuming 4–8 hours/day of supervised autonomous operation. RL is the highest-risk, highest-reward arm in V2. Defer until V1 is rock-solid and the auto-reset infrastructure exists.

### 5.3 EE-space actions + URDF-based IK adapter

The current policy outputs joint-space targets. EE-space (end-effector pose deltas + gripper width delta) has three benefits:
- Cleaner action representation for tasks that are intrinsically EE-defined (insertion, alignment, surface-following).
- Decouples policy learning from kinematics — if the gantry chain changes (e.g. wrist_pitch is replaced), an EE-space policy is unaffected; a joint-space policy needs retraining or a remapping.
- Required (or strongly preferred) by every open VLA stack — keeps the door open to OpenVLA-OFT / pi0 fine-tuning if priorities shift.

What this entails:
1. **Forward kinematics** from the URDF in [urdf/](../../urdf/). Straightforward — pinocchio or ikfast or urdfpy. Use it to compute EE pose from `qpos` at every demo timestep, store as an additional dataset field.
2. **Inverse kinematics** that is fast enough to run inline in the inference loop (target ≤ 1 ms per call). On a 6-DOF arm without redundancy this is analytical; on a 7-DOF (gantry + wrist) chain there's nullspace freedom. Options: ikfast (analytical when possible), TRAC-IK (fast numerical), Pinocchio's quadprog-based IK. We have a redundant chain (gantry has 3-DOF planar + 3-DOF wrist + 1-DOF gripper); ikfast may not solve it cleanly. Plan for TRAC-IK or Pinocchio.
3. **Action representation**: EE pose as 6D (position + 6D rotation per Zhou et al. — avoids Euler/quat singularities) + gripper width = 7 values. Same dimensionality as joint-space, but different semantics.
4. **Training**: keep V1 architecture; change only the action target. Train both joint-space and EE-space versions on the same demos for a controlled comparison.
5. **Inference loop change**: per chunk-step, run IK on the predicted EE chunk, convert to joint targets, feed to the existing motor-control interface. Latency budget tightens by the IK call cost (~1 ms × chunk-step length); should still fit.
6. **Safety**: existing joint-limit clamps still apply post-IK. Add an explicit EE-workspace box for an additional layer.

Expected effort: 2–3 weeks. The IK is the critical-path item; everything else is incremental.

If V1 doesn't show a smoothness or kinematics failure mode that EE-space would address, this arm is genuinely optional — joint-space is fine for many tasks. Keep it warm; promote to V2 only if the V1 result motivates it (e.g. if V1 struggles on contact-aligned subtasks).

---

## 6. Risk register

Sized for actual project risks, not borrowed from the original plan.

| # | Risk | Likelihood | Impact | Mitigation |
|---|---|---|---|---|
| 1 | Diffusion sampling latency exceeds the per-chunk control budget on Jetson Orin Nano | Medium | High | Reduce inference frequency (re-plan every 8–16 control steps). Reduce DDIM steps. Profile early — do not commit to V1 deploy until offline latency is measured. |
| 2 | V1 doesn't beat the ACT baseline | Low–Medium | Medium | Acceptable outcome at parity. If clearly worse, re-collect with more multi-modality before adding research arms — the cause is almost always the data, not the architecture. |
| 3 | Diffusion training is unstable with `grad_clip=0.1` (current default for ACT) | Medium | Low | Bump to 1.0 for diffusion; ablate. |
| 4 | The 200-demo collection session reveals hardware/calibration drift, poisoning the dataset | Medium | High | Spot-check every 25 demos with view_episode.py. Re-zero/re-mirror the leader at session boundaries. Discard any episodes that fail manual review. |
| 5 | The chosen V1 task lacks multi-modality, blunting the comparison vs. ACT | Medium | Medium | Pick a task where the human can grasp/place from multiple angles. If V1 looks like parity for this reason, add multi-modal demonstrations explicitly (different grasp strategies for the same start). |
| 6 | Real-robot RL (V2.5) damages the robot during exploration | High *if attempted* | High | Don't attempt without a hardened safety envelope, working auto-reset, and a breakage budget. Use RLPD (hybrid online + offline replay) and a KL penalty to V1; never run online RL without that regularizer. |
| 7 | The harmonic basis arm kills high-frequency components of the gripper action and reduces grasp success | Medium | Low (it's an optional arm) | Per-joint K, or skip the gripper joint in the harmonic projection. |
| 8 | Auto-reset is harder than expected, blocking the RL arm | Medium | Medium | The auto-reset subproject is on the V2.5 critical path. Scope it explicitly; budget 1–2 weeks for it as a precondition to RL. |
| 9 | The IK on the redundant gantry chain is non-trivial; nullspace handling produces inconsistent joint configurations between chunk-steps | Medium *if EE-arm attempted* | Medium | Use TRAC-IK or Pinocchio; seed each IK call with the previous joint solution to keep continuity in nullspace. |

The original plan listed risks for wearable-device SLAM and a 7B model that don't apply here. Risk #6 is the one borrowed from the original plan that *does* apply.

---

## 7. Timeline

Honest, single-developer estimates. V1.0 (task selection + demo collection) and V1.1 (diffusion head implementation) run in parallel because they're independent.

| Phase | Duration | Milestone |
|---|---|---|
| V1.0 — Pick task, collect ~200 demos | 1–2 days (operator time) over a week | `episodes/{task_name}/` populated; ≥95% manual-review pass rate |
| V1.1 — Diffusion head implementation (parallel with V1.0) | 1–2 weeks | `--policy diffusion` flag works in train.py; checkpoint loads in evaluate_policy.py |
| V1.2 — Hyperparameter sweep + offline eval | 1 week | Best diffusion checkpoint within 10% of ACT mean L1 on held-out validation |
| V1.3 — Latency profiling + chunk-step tuning | 3 days | Per-chunk inference latency budget verified on Jetson |
| V1.4 — Hardware dry-run + live deployment | 1 week | 20-trial success-rate comparison ACT vs. Diffusion on the V1 task |
| V1.5 — Comparison report | 2 days | Document filed at `docs/learning/V1_RESULTS.md`; includes success rate, cycle time, RMS jerk, qualitative perturbation behavior |
| **V1 total** | **~5–6 weeks** | |
| V2 — pick a research arm | (decision based on V1.5) | Per the §4 table: harmonic basis, RL post-training, or EE-space + IK |
| V2 execution | 1–4 weeks (harmonic) / 3–6 weeks (RL) / 2–3 weeks (EE-space) | Per arm |
| **First V2 result** | **~7–12 weeks from start** | |

Compare to the original plan's "12–15 months to first autonomous deployment" — that timeline assumed greenfield wearable hardware, 50k–500k hours of crowd data, and a 7B model. None of which apply.

---

## 8. Required reading (revised)

The original plan's reading list was good for the founder-genealogy / frontier-lab angle but heavy on speculative architectural inferences. The list below is sized for the V1/V2 path.

**Primary, blocking:**
- Chi et al. (2023). *Diffusion Policy: Visuomotor Policy Learning via Action Diffusion.* RSS 2023. — V1 architecture.
- Zhao et al. (2023). *Learning Fine-Grained Bimanual Manipulation with Low-Cost Hardware (ALOHA / ACT).* RSS 2023. — Our current baseline.
- Zhao et al. (2024). *ALOHA Unleashed: A Simple Recipe for Robot Dexterity.* CoRL 2024. — Concrete example of the ACT → Diffusion upgrade.

**For V2 research arms (read when picking the arm):**
- Liu et al. (2024). *Fourier Flow Matching.* NeurIPS 2024. — If picking the harmonic basis arm.
- Ball et al. (2023). *Efficient Online Reinforcement Learning with Offline Data (RLPD).* — If picking the RL arm. The most robust real-robot recipe in the recent literature.
- Nakamoto et al. (2023). *Cal-QL: Calibrated Offline RL Pre-Training for Efficient Online Fine-Tuning.* NeurIPS 2023. — Read alongside RLPD; understand the failure modes before choosing between them.
- Zhou et al. (2019). *On the Continuity of Rotation Representations in Neural Networks.* — If picking the EE-space arm; defines the 6D rotation representation we should use.
- Beeson & Ames (2015). *TRAC-IK: An Improved Inverse Kinematics Solver.* — If picking the EE-space arm; a likely IK solver pick.

**Background, contextual:**
- Florence et al. (2022). *Implicit Behavioral Cloning.* ICLR 2023. — Read to understand why we are *not* using EBM/InfoNCE at our action dim.
- Black et al. (2024). *pi0: A Vision-Language-Action Flow Model for General Robot Control.* arXiv 2410.24164. — Worth reading once for the flow-matching framing, even though we're not using pi0.

**Skip unless priorities change:**
- OpenVLA-OFT and pi0.5 papers — relevant only if VLA fine-tuning is reinstated as a V2 path.
- Anything on UMI / wearable data collection — not our setting.
- Florence's Implicit BC follow-ups — superseded for our action dim.
- PaLM-E / RT-2 — closed; not actionable.
- Generalist GEN-0/GEN-1 blogs — interesting but architecturally undisclosed; nothing to copy from.

---

## 9. Decisions made (2026-04-30)

The structuring questions in the previous draft of §9 were answered by the user before this revision:

| Question | Decision |
|---|---|
| Primary goal of the next 3–6 months | **Robust task performance.** V1 = Diffusion Policy on AIZEE; V2 = research arms on top of V1. Frontier-lab-style architectural novelty is explicitly *not* the goal. |
| Task scope for V1 evaluation | **One narrow, well-scoped task.** Strong default candidate: single-object pick-and-place on a marked target (see §3.0). |
| Demo collection cadence | **Fast — 200+ demos in 1–2 focused sessions.** This unlocks aggressive data scale-up as a baseline rather than as a separate phase. |
| Stretch arms kept on the books | **Harmonic basis, EE-space + IK adapter, RL post-training.** Third overhead camera explicitly *out* — Generalist's deployments work without one, and we'd rather spend the engineering on the kept arms. |

Open items that should be re-examined as V1 progresses:

1. **Specific task choice.** §3.0 names a strong default (pick-and-place on a marked target), but the user should pick the actual physical object/zone before V1.0 demo collection starts. This is the one decision still owed.
2. **Whether to keep VLA fine-tuning on the books at all.** The current plan demotes it to "skip unless priorities change." If V1 plateaus and none of the three research arms close the gap, reconsider — OpenVLA-OFT remains the documented 2025 SOTA fine-tune recipe.
3. **What "robust" means quantitatively.** Concrete success-rate target on the V1 task (e.g. ≥95% over 100 trials) should be set when the task is chosen, before V1 evaluation begins. Without a target, "robust" is a ratchet that never closes.
4. **Whether the V2 arm picked from §4 is sequential or parallel.** Default: sequential (one arm at a time). Harmonic basis is cheap enough to run in parallel with another, if the operator wants to.

---

*This is a working hypothesis. Treat it as a baseline to be revised as V1 lands and the comparison data comes back.*

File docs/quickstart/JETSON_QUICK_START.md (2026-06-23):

# Jetson Quick Start

Daily-driver reference for connecting to the AIZEE robot and running teleop or
data collection. Run all dev-machine commands from the repo root.

The on-robot brain is a **Jetson Orin Nano** (JetPack 6.x). All robot
subsystems run as systemd services that auto-start on boot, so after power-up
you usually just connect, glance at the dashboard, and run.

## Modes

| Mode | What runs | Notes |
|---|---|---|
| ROVER  | Wheels + arm | Full mobile manipulator |
| STATIC | Arm only (+ scene cam) | Wheels idle; optional subsystems auto-detect |

Optional subsystems (gripper cam, scene cam, LiDAR) auto-detect — you don't
select a mode explicitly.

## 1. Connect

Three ways to reach the Jetson. The operator tools auto-resolve in this
priority order, so usually you don't pick one manually:

| Priority | Path | IP |
|---|---|---|
| 1 | LAN / WiFi client | `192.168.0.27` |
| 2 | USB-C ethernet (tether) | `10.42.0.1` |
| 3 | WiFi AP `aizee` (robot's own network) | `192.168.50.1` |

SSH in with:

```bash
ssh -i ssh-keys/aizee_rover_id ltr@<ip>
```

(user is `ltr`).

## 2. First check — the heartbeat dashboard

Before anything else, open the dashboard in a browser:

```
http://<jetson-ip>:8088
```

- Over USB-C: <http://10.42.0.1:8088>
- Over the AP: <http://192.168.50.1:8088>
- On the LAN:  <http://192.168.0.27:8088>

It shows service status, recent journald logs, host metrics (CPU/mem/disk/
thermal), and live robot telemetry (motors, batteries, cameras). This replaces
ad-hoc status checks — if everything is green here, you're ready to run.

## 3. Run teleop

From the dev machine, repo root:

```bash
python python/teleop/teleop.py
```

Endpoints come from `config/teleop.yaml` (default). Useful flags:

| Flag | Effect |
|---|---|
| `--keyboard-only` | Disable gamepad |
| `--endpoint tcp://IP:5555` | Override command endpoint |
| `--config path/to.yaml` | Use a different config |
| `--log-level DEBUG` | Verbose logging (to `teleop.log`) |

### Controls

| Key | Action |
|---|---|
| WASD | Drive (forward / back / turn) |
| E | Enable all motors |
| Q | Disable all motors |
| Back btn | Emergency stop (gamepad) |
| Start btn| Clear E-stop + faults (gamepad) |
| ESC | Exit |

Gamepad: A = enable, B = disable, Back = E-stop, Start = clear E-stop/faults,
left stick = drive.

## 4. Collect demonstration data

A leader arm (SO-101, OpenRB-150, or Quest VR) drives the arm while episodes
are recorded. From the dev machine, repo root:

```bash
python python/scripts/collect_demo.py --gui
```

The rover IP, leader device, and scene camera are all **auto-detected**:

- `--gui` opens the Qt viewer (omit for the terminal renderer).
- `--leader openrb|so101|quest` forces a specific leader kind (default `auto`).

Common recording controls:

| Key  | Action |
|---|---|
| E | Enable arm motors (align to leader) |
| R | Toggle recording |
| H | Hold target at current position |
| Z | Capture current leader pose as zero reference |
| X | Soft shutdown (return to zero, disable) |
| Q | Quit |
| WASD | Drive wheels (enable with arm) |

## Telemetry quick test

Confirm the Jetson is publishing motor telemetry:

```bash
python -c "import zmq,json;c=zmq.Context();s=c.socket(zmq.SUB);s.connect('tcp://10.42.0.1:5556');s.setsockopt(zmq.SUBSCRIBE,b'');print(s.recv())"
```

(Swap the IP for whichever path you connected over.)

## Ports & motors at a glance

ZMQ on the Jetson: `:5555` commands, `:5556` telemetry, `:5562` UPS,
`:5563` gripper cam, `:5564` scene cam, `:8088` heartbeat dashboard.

9× ROBSTRIDE motors on `can1` @ 1 Mbps:

| Motor | CAN ID | Motor | CAN ID |
|---|---|---|---|
| left_wheel  | 0x02 | gantry_mid | 0x06 |
| right_wheel | 0x04 | gantry_end | 0x07 |
| swivel | 0x03 | wrist_pitch  | 0x08 |
| gantry_base | 0x05 | wrist_roll | 0x09 |
| | | gripper | 0x0A |

For post-reboot verification, service management, and troubleshooting, see
[QUICK_START_AFTER_REBOOT.md](QUICK_START_AFTER_REBOOT.md).

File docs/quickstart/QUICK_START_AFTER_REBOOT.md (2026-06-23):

# Quick Start After Jetson Reboot

Verify the robot came up cleanly after a reboot, manage its services, and
troubleshoot. For everyday connect-and-run, see
[JETSON_QUICK_START.md](JETSON_QUICK_START.md).

## What happens on boot

On-robot subsystems run as systemd services and **auto-start on boot**, so a
reboot normally needs no manual setup:

| Service | Role |
|---|---|
| `aizee-motor-control-rover` | Configures `can1` + runs control loops  |
| `aizee-gripper-cam` | ELP UVC gripper camera (`:5563`) |
| `aizee-scene-cam` | RealSense scene camera (`:5564`) |
| `aizee-ups-monitor` | UPS battery telemetry (`:5562`) |
| `aizee-heartbeat` | Dashboard on `:8088` |
| `aizee-display` | Tufty2040 status display |
| `aizee-estop-bridge` | Hardware E-stop bridge |

`aizee-lidar-control` is often disabled. Optional camera subsystems auto-detect
their hardware, so missing devices degrade gracefully.

The motor control service runs CAN init + control loops: arm @ 400 Hz, base @
100 Hz, telemetry @ 50 Hz.

## 1. First check — the dashboard

Open the heartbeat dashboard:

```
http://<jetson-ip>:8088
```

(e.g. <http://10.42.0.1:8088> over USB-C, <http://192.168.50.1:8088> over the
AP, <http://192.168.0.27:8088> on the LAN). It shows service status, recent
journald logs, host metrics, and live telemetry. If everything is green, you're
done — start teleop or data collection per
[JETSON_QUICK_START.md](JETSON_QUICK_START.md).

Alternatively, from the dev machine repo root:

```bash
./scripts/check_rover_status.sh
```

This checks network reachability, the CAN interface, the motor control service,
and live telemetry.

## 2. Confirm telemetry

```bash
python -c "import zmq,json;c=zmq.Context();s=c.socket(zmq.SUB);s.connect('tcp://10.42.0.1:5556');s.setsockopt(zmq.SUBSCRIBE,b'');print(s.recv())"
```

Swap the IP for whichever path you connected over. No data within a few seconds
means the motor control service isn't publishing — see troubleshooting below.
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

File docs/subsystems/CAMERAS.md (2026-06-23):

# Camera System

AIZEE runs up to two cameras, both connected directly to the Jetson via USB and
published over ZMQ. The gripper camera is the **primary observation** and is
always present; the scene camera is **optional** and auto-detected at runtime.

| Camera | Sensor | Node | Config | ZMQ ports |
|---|---|---|---|---|
| gripper_cam | ELP-USBFHD01M-L21 (USB UVC) | `python/nodes/gripper_camera_node.py` | `config/hardware_jetson_gripper_cam.yaml` | PUB `:5563`, control REP `:5573` |
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

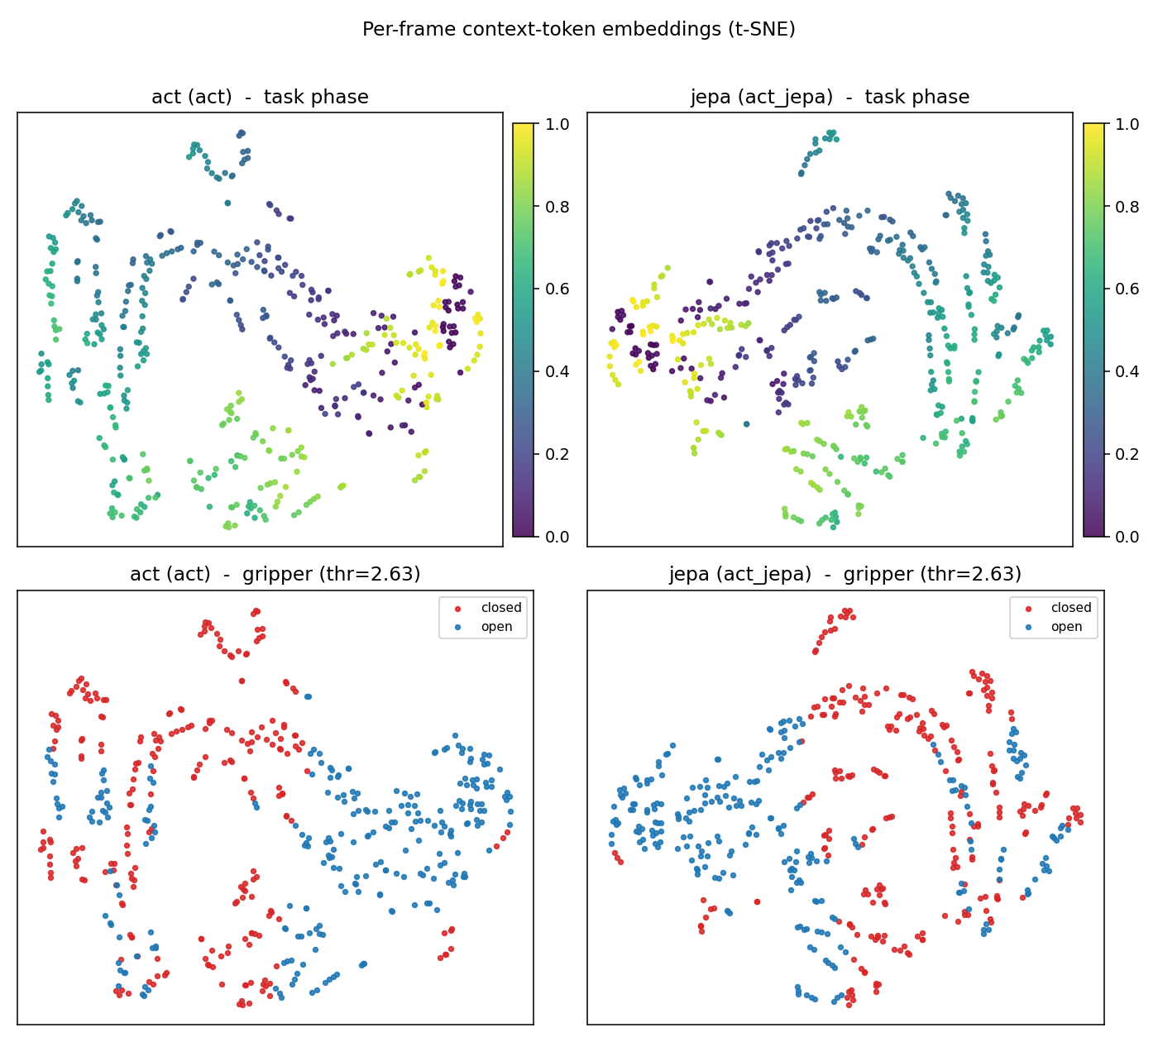
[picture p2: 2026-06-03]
viz/embeddings.png

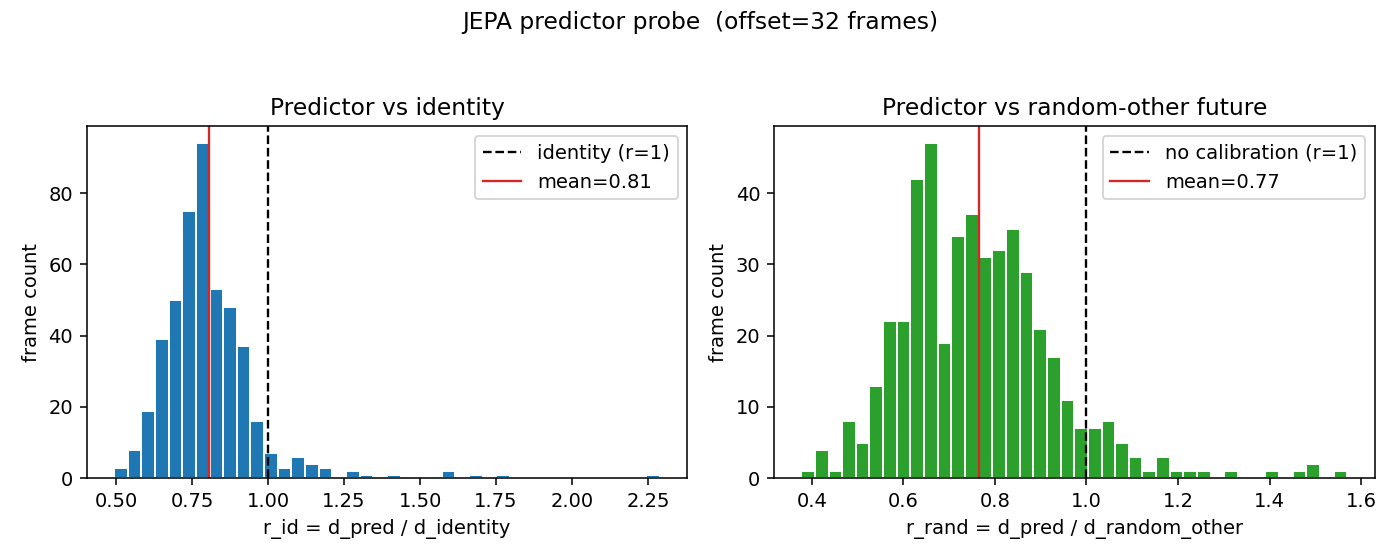
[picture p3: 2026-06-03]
viz/probe.png

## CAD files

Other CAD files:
urdf/aizee/meshes/part_70.stl
urdf/aizee/meshes/part_64.stl
urdf/aizee/meshes/rplidar_a1m8.stl
urdf/aizee/meshes/tophalfbase.stl
urdf/aizee/meshes/1_1_02_eb571_960_stp.stl
urdf/aizee/meshes/part_43.stl
urdf/aizee/meshes/1_1_06_eb573_642_stp__2.stl
urdf/aizee/meshes/part_1.stl
urdf/aizee/meshes/1_1_02_eb1201_501_1_1_1__2.stl
urdf/aizee/meshes/linearrail_lwl7b_100mm__2.stl
urdf/aizee/meshes/part_11.stl
urdf/aizee/meshes/part_2.stl
urdf/aizee/meshes/1_1_06_eb673_516_1_stp.stl
urdf/aizee/meshes/part_39.stl
urdf/aizee/meshes/gyos72_17_93_i__1_1_1.stl
urdf/aizee/meshes/1_1_04_eb572_5105_stp.stl
urdf/aizee/meshes/part_41.stl
urdf/aizee/meshes/part_40__2.stl
urdf/aizee/meshes/1_1_02_eb1201_501_1_1_1.stl
urdf/aizee/meshes/1_1_02_eb1201_501_1_1_1__3.stl
urdf/aizee/meshes/1_1_02_eb571_960_stp__2.stl
urdf/aizee/meshes/1_1_02_eb671_502_1_stp.stl
urdf/aizee/meshes/1_1_02_eb901_547_1.stl
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

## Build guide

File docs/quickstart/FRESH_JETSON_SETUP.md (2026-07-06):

# Fresh Jetson Orin Nano Setup

From a blank SD card to a fully validated robot brain. The interactive version
of this checklist lives on the robot itself once the heartbeat service is up:
**http://\<jetson\>:8088/setup**.

## 0. What you need

- Jetson Orin Nano + SD card (or NVMe), JetPack **6.x**
- The USB-CAN adapter (gs_usb, 1 Mbps) — it has a physical power switch
- This repo checked out on the dev machine, git-bash available
- The `aizee_rover_id` SSH keypair (`ssh-keys/` in the Workspace); a fresh key
  also works — the bootstrap installs whatever `SSH_KEY` points at

## 1. Flash JetPack

Flash with SD Card Formatter + Balena Etcher (SD image) or NVIDIA SDK Manager.
During first-boot **oem-config**:

- user: `ltr` (everything — services, paths, sudoers — assumes it)
- connect WiFi or ethernet: the bootstrap needs internet on the device
- hostname: anything; the bootstrap can set `aizee-jetson` for you

USB-C to your PC gives a fallback network path at `192.168.55.1`
(JetPack device mode) before any of our networking is configured.

## 2. Bootstrap (one command from the dev machine)

```bash
./scripts/bootstrap_jetson.sh ltr@192.168.55.1 -- --ap-pass '<wifi-psk>' --hostname aizee-jetson
```

This installs your SSH key (one password prompt), syncs `rust/ config/
scripts/ python/ firmware/` to `~/aizee`, and runs `scripts/setup_jetson.sh`
on the device, which does — idempotently:

| step | what |
|---|---|
| apt | `can-utils i2c-tools v4l-utils python3-pip python3-dev python3-opencv python3-smbus build-essential pkg-config libzmq3-dev curl git` |
| groups | adds `ltr` to `i2c dialout video` |
| rust | rustup (minimal) if `cargo` is missing |
| python | `pip install --user -r requirements_jetson.txt`; tries `pyrealsense2` (warn-only) |
| CAN | `/usr/local/bin/aizee-reset-usb-can` + `/etc/sudoers.d/aizee-can` |
| udev | all of `config/udev/` (lidar rules only with `--with-lidar`) |
| systemd | installs **all** `aizee-*` units, enables boot + device-bound services |
| build | `cargo build --release` for motor_control (several minutes the first time) |
| network | WiFi AP `aizee` @ `192.168.50.1` (`--ap-pass`), optional USB-C share @ `10.42.0.1` (`--usb-eth <iface>`) |

Re-run any time: `./scripts/bootstrap_jetson.sh` (auto-detects the reachable
address). For code-only refreshes use `./scripts/deploy_jetson_rover.sh`.

> **Re-flashed device?** The SSH host key changed — run
> `ssh-keygen -R <address>` first.

## 3. Wire the hardware

- **CAN**: adapter powered ON, motors chained, 30 V pack on. Every motor listed
  in `config/hardware_jetson_rover.yaml` must be on the bus or `motor_control`
  wedges during init. Wheels physically absent → set `motors.wheels: []`
  (keep the key — the Rust config parser requires it).
- **USB**: gripper cam (ELP), scene cam (RealSense, optional — its absence just
  means "rover mode" v4 episodes), Tufty display (optional), e-stop receiver
  (optional). Order doesn't matter; udev symlinks + starts services on plug-in.
- **UPS**: INA219 on i2c bus 7, addr 0x41.

## 4. Validate

Open **http://192.168.50.1:8088/setup** (AP) or `http://10.42.0.1:8088/setup`
(USB-C share) and hit *Run all checks* — python deps, rust build, services,
CAN state, device symlinks, live motor/UPS/camera telemetry, network. Every
failing check carries its own fix hint.

Headless equivalent over SSH (exit code 1 on failure):

```bash
ssh ltr@10.42.0.1 'python3 ~/aizee/python/tools/setup_checks.py'
```

Old-school one-shot from the dev machine: `./scripts/check_rover_status.sh`.

## 5. Teleop smoke test (dev machine)

```bash
python python/scripts/collect_demo.py --gui
```

`E` engage → arm mirrors the leader → `R` record a short episode → `Q` quit.
Episode lands in `data/episodes/`. If the arm doesn't engage, check the
heartbeat dashboard first: E-stop tile, motor table, then service logs.

## Known sharp edges

- **USB-CAN adapter drops off the bus** occasionally (gone from `lsusb`) —
  power-cycle it with its physical switch; software can't recover it.
- **pyrealsense2 has no reliable aarch64 wheel** — if pip fails the scene cam
  stays off until you build it: `scripts/build_librealsense_rsusb.sh`.
- **Group membership** (i2c/dialout/video) applies to *new* logins; systemd
  services are unaffected, but interactive debugging needs a re-login after
  first setup.
- Shell scripts synced from Windows carry CRLF; `setup_jetson.sh` strips them
  for everything it installs, and `.gitattributes` now forces LF at checkout.

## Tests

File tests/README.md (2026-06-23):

# AIZEE Test Scripts

This directory contains test scripts for validating motor control and system integration.

## Directory Structure

```
tests/
├── direct_can/         # Low-level CAN protocol tests (Python only, no Rust binary)
├── integration/        # Full system tests (Rust motor_control + ZeroMQ)
└── utils/             # Utilities for debugging and development
```

## Current Test Setup

**Hardware:**
- ROBSTRIDE03 (CAN ID 0x02) - Mapped as "right_wheel"
- ROBSTRIDE04 (CAN ID 0x03) - Mapped as "left_wheel"
- Configuration: `config/hardware_two_motors.yaml`

**Prerequisites:**
- CAN interface configured: `sudo ./scripts/setup_can.sh`
- Rust motor_control built: `cd rust/motor_control && cargo build --release`
- Python dependencies: `pip install python-can pyzmq`

## Tests

### Direct CAN Tests (`direct_can/`)

These tests communicate directly with motors via CAN bus without using the Rust binary.

#### `motor_control_test.py`
Low-level motor control with tuned PD gains.

**Features:**
- Direct CAN protocol implementation
- Tuned gains: Kp=3.0, Kd=0.3 (smooth motion, no vibrations)
- Proper signal handling (SIGINT/SIGTERM)
- Auto-disable on exit (safe for testing)

**Usage:**
```bash
# On Jetson
cd ~/aizee/tests/direct_can
./motor_control_test.py
# Press Ctrl+C to stop
```

**Note:** Only use for testing. Production systems should keep motors enabled to prevent dropping loads.

---

### Integration Tests (`integration/`)

These tests run the full Rust motor_control binary with ZeroMQ command interface.

#### `test_both_motors.sh`
Tests both motors together with zero positioning.

**What it does:**
1. Starts motor_control binary with two-motor config
2. Enables both motors
3. Zeros positions
4. Drives forward at 0.3 rad/s for 4 seconds
5. Stops and disables motors
6. Cleans up processes

**Usage:**
```bash
# On Jetson
cd ~/aizee/tests/integration
./test_both_motors.sh
```

**Output:** Log written to `/tmp/zeroed_test.log`

#### `test_individual.sh`
Tests each motor separately to validate individual motor operation.

**What it does:**
1. Tests ROBSTRIDE03 (ID 2, "right_wheel") alone
2. Tests ROBSTRIDE04 (ID 3, "left_wheel") alone
3. Each motor: enable → zero → spin @ 0.5 rad/s → stop → disable

**Usage:**
```bash
# On Jetson
cd ~/aizee/tests/integration
./test_individual.sh
```

**Output:** Log written to `/tmp/individual_test.log`

---

### Utilities (`utils/`)

#### `scan_all_motors.py`
Scans CAN bus for all connected motors (IDs 1-127).

**Usage:**
```bash
# On Jetson
cd ~/aizee/tests/utils
python3 scan_all_motors.py
```

**Output:**
```
Scanning all IDs 1-127...
✓ Found motor at CAN ID 2 (0x02)
✓ Found motor at CAN ID 3 (0x03)

Found 2 motor(s): [2, 3]
```

#### `send_zmq_command.py`
Send individual ZeroMQ commands to running motor_control process.

**Usage:**
```bash
# Start motor_control first, then:
python3 send_zmq_command.py

# Modify the script to send different commands:
# - {"type": "enable", "motor_ids": ["left_wheel"]}
# - {"type": "drive", "linear": 0.5, "angular": 0.0}
# - {"type": "disable", "motor_ids": ["left_wheel"]}
```

#### `capture_can_frames.sh`
Wrapper for `candump` to capture CAN traffic for debugging.

**Usage:**
```bash
# On Jetson
cd ~/aizee/tests/utils
./capture_can_frames.sh
# Press Ctrl+C to stop
```

---

## Proven Control Parameters

### ROBSTRIDE03 (Position Control)
- **Kp**: 3.0 - Smooth motion without vibrations
- **Kd**: 0.3-0.8 - Good damping, minimal oscillation
- **Frequency**: 50-100 Hz
- ⚠️ **Note**: Higher gains (Kp=20, Kd=2) cause vibrations

### ROBSTRIDE04 (Velocity Control)
- **Linear velocity**: 0.15-0.5 rad/s (tested via "drive" commands)
- **Zero position**: Working correctly
- **Control frequency**: 100 Hz (base loop)

---

## Common Issues

### CAN interface not found
```bash
sudo ./scripts/setup_can.sh
```

### Permission denied on CAN socket
```bash
sudo usermod -aG dialout $USER
# OR run tests with sudo (not recommended)
```

### Motor not responding
1. Check CAN wiring
2. Verify motor is powered
3. Scan for motors: `python3 tests/utils/scan_all_motors.py`
4. Check CAN traffic: `./tests/utils/capture_can_frames.sh`

### Rust binary not found
```bash
cd ~/aizee/rust/motor_control
cargo build --release
```

---

## Development Workflow

### Testing a new feature:
1. Write unit tests in `rust/motor_control/tests/`
2. Build: `cargo build --release`
3. Test individual components with utilities
4. Run integration tests
5. Monitor CAN traffic if issues occur

### Before committing changes:
1. Run all integration tests
2. Verify both motors respond correctly
3. Check logs for errors
4. Update this README if adding new tests

---

## Related Documentation

- Main project: `../README.md`
- Documentation hub: `../docs/README.md`
- Implementation phases: `../docs/PHASES.md`
- Hardware config: `../config/hardware_two_motors.yaml`

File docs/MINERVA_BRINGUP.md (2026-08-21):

# Minerva Arms Bring-Up (Path A — two instances, dual GELLO)

Bring up the two 6+1-DoF Minerva arms for **calibration + dual-GELLO teleop**, with
no head/lift/URDF/cameras. Each arm is a self-contained motor_control instance on
its own CAN bus and ZMQ port pair; the two arms are identical (motor ids 4..10) and
are told apart only by their bus. The laptop-side tools **auto-detect the Jetson** the
same way collect_demo does — LAN `192.168.0.27` → USB-C direct `10.42.0.1` → WiFi AP
`192.168.50.1` — so `--host` is optional (it just sets which address to try first).

| Arm | CAN bus | cmd port | telem port | motor_control config / service |
|---|---|---|---|---|
| left  | `canL`  | 5555 | 5556 | `hardware_minerva_left.yaml`  / `aizee-minerva-left`  |
| right | `canR`  | 5575 | 5576 | `hardware_minerva_right.yaml` / `aizee-minerva-right` |

- **CAN names are udev-pinned by physical USB port** (`config/udev/80-minerva-can.rules`):
  `canL`=USB 1-2.1.2, `canR`=USB 1-2.1.4. The internal Tegra mttcan owns the unused
  `can0`. Distinct names (not canN) avoid rename-swap between the two identical gs_usb
  adapters.
- **Right ports are 5575/5576** (not 5557–5560 — those are held by `aizee-camera-relay`).
- Joint order per arm (arm-group = swivel idx0 + arm[]):
  `j1(id4) j2(id5) j3(id6) j4(id7) j5(id8) j6(id9) gripper(id10)`. Shoulder id-4 = **RS03**
  (confirmed); ids 5–10 mirror the AIZEE arm.

---

## 0. Deploy (from the dev machine)

```bash
./scripts/deploy_minerva_arms.sh          # builds motor_control, installs both
                                          # services + udev rule + aizee-can-up +
                                          # sudoers; retires the rover service; does
                                          # NOT start (start only with the bus powered)
```
Services install **enabled for boot** (validated on hardware). They auto-start on boot;
the degraded-mode recovery makes a boot with motors off safe (idles, doesn't wedge). To
start now without rebooting, use step 1. To opt out of boot-start:
`sudo systemctl disable aizee-minerva-left aizee-minerva-right`.

## 1. Start the follower instances (Jetson, motors POWERED)

```bash
sudo systemctl start aizee-minerva-left aizee-minerva-right
```
Each runs `aizee-can-up` (brings its udev-named bus up at 1 Mbps — **no** USB unbind/
rebind) then motor_control. A healthy bus shows balanced RX≈TX and `state ERROR-ACTIVE`
with 0 bus-off (`ip -s -d link show canL`).

## 2. Mechanically zero the RobStrides (once per new build)

Sets each motor's firmware mechanical zero + SaveConfig so encoder zero is
repeatable across power cycles. Run the teleop tool, keep arms **DISABLED**, press **K**:
```bash
python python/scripts/minerva_teleop.py --host <jetson-ip> --dry-run
# press K  (mech_zero sent to both arms), then Q
```
(`--dry-run` still sends K; it only blocks enable/motion.) Power-cycle-safe afterward.

## 3. Calibrate the follower min/max

Move each joint to its physical min then max; positions are recorded under
zero-impedance. Writes `config/minerva_calibration.json`.
```bash
python python/scripts/minerva_calibrate.py --host <jetson-ip>
# per arm:  E (enable free-move) -> C (start) -> SPACE at each min/max
```

## 4. Calibrate the two GELLO leaders

Each OpenRB-150 leader needs its own file (servo min/max/zero differ per unit):
```bash
python python/scripts/openrb_calibrate.py --port <left-port>  --output config/openrb_left.json
python python/scripts/openrb_calibrate.py --port <right-port> --output config/openrb_right.json
```

## 5. Teleop — terminal tool OR the GUI collector

Both front-ends share the same controls + both zero functions. The GUI drives the
two instances directly (`collect_minerva_app/follower.py`) and adds 3 cameras + v6
recording.

Terminal (no cameras/recording):
```bash
python python/scripts/minerva_teleop.py --host <jetson-ip> \
    --left-calib config/openrb_left.json --right-calib config/openrb_right.json
```
GUI collector:
```bash
python python/scripts/collect_minerva.py --host <jetson-ip> \
    --left-calib config/openrb_left.json --right-calib config/openrb_right.json
```
First registration: press **Z** (leader-zero) or **M** (mirror) so the leaders map to
the arms, then **E** to track (or **I** to backdrive and read positions). Both default
to `--kp-scale 0.3`; raise once tracking looks right.

---

## Controls (mirrors collect_demo) — IDLE-FIRST

**Sequence, every session: Idle → zero → Enable.** Idle (zero torque) is always the
first action — it reports live actuator state safely. These RobStrides can **lose their
zeros**, so you read state and re-zero (RobStride mech `K` + GELLO `Z`/`M`) **before**
applying any gains. **Enable is gated: it only works from Idle.**

| Key | Action |
|-----|---|
| `I` | **idle — enable at ZERO torque. ALWAYS FIRST** (read positions, limp/backdrivable) |
| `E` | enable gains → HOLD. **Only from Idle** (after zeroing); blocked from DISABLED |
| `H` | toggle HOLD ↔ TRACKING |
| `Z` | **leader zero** — snapshot each leader pose as its zero; save to calib |
| `M` | **mirror** — set each leader zero so it maps to the arm's current pose; save |
| `K` | **RobStride mechanical zero** + SaveConfig, both arms (disable first) |
| `P` | save current pose → `config/minerva_ready_pose.json` |
| `X` | soft shutdown — ramp both arms to zero, then disable |
| `Q` | quit |

Absolute leader mapping: `target = direction · (leader_rad − zero)` per joint; a
per-step velocity guard bounds every command so engaging never snaps.

## Files

- `config/hardware_minerva_{left,right}.yaml` — follower instance configs
- `config/minerva_calibration.json` — follower min/max (step 3)
- `config/openrb_{left,right}.json` — per-leader calibration (step 4)
- `python/scripts/minerva_calibrate.py` — follower min/max wizard
- `python/scripts/minerva_teleop.py` — terminal dual-GELLO teleop + zero functions
- `python/scripts/collect_minerva.py` (+ `collect_minerva_gui.py`) — GUI collector
- `collect_minerva_app/follower.py` — `DualArmTransport` (two instances → one 17-vec)
- `collect_minerva_app/teleop.py` — `MinervaTeleop` absolute mapping + Z/M zeros

## Integrated into the GUI

The controls + both zeros are wired into the `collect_minerva` GUI (buttons +
E/I/H/T/R/Z/M/K/P/X/Q shortcuts). It keeps the 17-DoF data model with head/lift
(indices 14..16) held at zero until that hardware exists, and drives the two
instances via `DualArmTransport`.

## Idle / telemetry probe (non-interactive)

```bash
python python/scripts/minerva_motor_probe.py --host 10.42.0.1 --arm both   # enable + zero-torque
python python/scripts/minerva_motor_probe.py --host 10.42.0.1 --no-enable  # telemetry only
```
This runs the same sequence as collect_demo's **Idle** (`enable`, then `arm_joints`
with kp=kd=torque=0 — motors energized but limp). RobStride MIT motors are **silent
until enabled**, so `0/7` while passive is normal; the enabled read is the real check.
Both arms validated **7/7 motors running** this way (left clean; right after the wiring
fix below).

## Hardware gotchas (learned on the bench)

- **Two identical gs_usb (candleLight 1d50:606f) adapters.** They're order-dependent,
  so we pin names by USB port via udev (above). Do **not** unbind/rebind them to recover
  (the old `aizee-reset-usb-can` path) — with two adapters it renames the wrong one and
  can drop an adapter off USB. `aizee-can-up` only does `ip link` up, never a USB reset.
- **Adapter drops off the bus under stress** (gone from `lsusb`, `ip link set … → "No such
  device"`). Software can't revive it — **power-cycle the adapter's physical switch**, or
  unplug/replug both. It re-enumerates on its port and udev re-names it. A rapid service
  restart-loop is what stresses it, so:
  - motor_control now **degrades instead of exiting** on persistent CAN failure (was:
    exit → systemd restart "with USB reset"). A dead/absent bus keeps the process alive
    (slow link-retry) so one arm's trouble can't knock the other's adapter offline.
  - the arm services have `StartLimitBurst=5/60s` so they can't flap.
- **CANH/CANL swapped** on an arm ⇒ **no ACK**: motor_control TX fails (`errno 105
  ENOBUFS`), `RX: 0 packets`, bus-off climbing — while a healthy arm shows balanced
  RX≈TX and 0 errors. That's how we found the right arm was miswired.
- **Latched fault after a CAN fault** (e.g., the miswiring): motors report `state=running`
  but carry a `MotorError` with *all* flags false. **Avoid `clear_fault`** — in testing it
  silenced the arm. Clear it with a **disable→re-enable** cycle or a motor power-cycle.
- **RobStride positions are multi-turn/absolute** (j5/j6 read ~6 rad near power-on); the
  min/max calibration (step 3) captures the usable range.

## Not yet in scope

Head/lift + waist actuators, a Minerva URDF, and the single-endpoint 17-DoF policy
path (`minerva_policy_node` still assumes one endpoint).

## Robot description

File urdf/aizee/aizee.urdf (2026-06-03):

<?xml version="1.0" ?>
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
<robot name="aizee">
  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
  <link name="tophalfbase">
    <inertial>
      <origin xyz="0 -0 0.137355" rpy="0 0 0"/>
      <mass value="0.384"/>
      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
    </inertial>
    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
  </link>
  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
  <link name="part_70">
    <inertial>
      <origin xyz="0 0 0" rpy="0 0 0"/>
      <mass value="0"/>
      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
    </inertial>
    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
  </link>
  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
  <joint name="left_wheel" type="continuous">
    <origin xyz="0.1495 -0 0" rpy="-1.5708 -0 1.5708"/>
    <parent link="tophalfbase"/>
    <child link="part_70"/>
    <axis xyz="0 0 1"/>
    <limit effort="10" velocity="10"/>
  </joint>
  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
  <link name="part_23">
    <inertial>
      <origin xyz="0 0 0" rpy="0 0 0"/>
      <mass value="0"/>
      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
    </inertial>
    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
  </link>
  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
  <joint name="right_wheel" type="continuous">
    <origin xyz="-0.1495 -0 0" rpy="1.5708 -0 1.5708"/>
    <parent link="tophalfbase"/>
    <child link="part_23"/>
    <axis xyz="0 0 1"/>
    <limit effort="10" velocity="10"/>
  </joint>
  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
  <link name="part_40">
    <inertial>
      <origin xyz="0 0 0" rpy="0 0 0"/>
      <mass value="0"/>
      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
    </inertial>
    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
  </link>
  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
  <link name="part_22">
    <inertial>
      <origin xyz="0 0 0" rpy="0 0 0"/>
      <mass value="0"/>
      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
    </inertial>
    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
  </link>
  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
  <link name="part_33">
    <inertial>
      <origin xyz="0 0 0" rpy="0 0 0"/>
      <mass value="0"/>
      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
    </inertial>
    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
  </link>
  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
  <link name="part_42">
    <inertial>
      <origin xyz="0 0 0" rpy="0 0 0"/>
      <mass value="0"/>
      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
    </inertial>
    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
  </link>
  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
  <link name="1_1_02_eb571_960_stp">
    <inertial>
      <origin xyz="0 0 0" rpy="0 0 0"/>
      <mass value="0"/>
      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
    </inertial>
    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
  </link>
  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
  <link name="1_1_02_eb571_960_stp_2">
    <inertial>
      <origin xyz="0 0 0" rpy="0 0 0"/>
      <mass value="0"/>
      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
    </inertial>
    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
  </link>
  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
  <joint name="wrist_swivel" type="revolute">
    <origin xyz="-0 -0.036 -0.071885" rpy="1.5708 -0 -0"/>
    <parent link="1_1_02_eb571_960_stp"/>
    <child link="1_1_02_eb571_960_stp_2"/>
    <axis xyz="0 0 1"/>
    <limit effort="10" velocity="10" lower="-3.141592653589793" upper="3.141592653589793"/>
  </joint>
  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
  <joint name="wrist_pitch" type="revolute">
    <origin xyz="-0.11497 0.00602531 0.0357124" rpy="0.0523599 1.5708 0"/>
    <parent link="part_42"/>
    <child link="1_1_02_eb571_960_stp"/>
    <axis xyz="0 0 1"/>
    <limit effort="10" velocity="10" lower="-3.141592653589793" upper="3.141592653589793"/>
  </joint>
  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
  <joint name="gantry_end" type="revolute">
    <origin xyz="-0.562406 -0.0420179 -0.00695" rpy="0 0 0.0546306"/>
    <parent link="part_33"/>
    <child link="part_42"/>
    <axis xyz="0 0 1"/>
    <limit effort="10" velocity="10" lower="-3.141592653589793" upper="3.141592653589793"/>
  </joint>
  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
  <joint name="gantry_mid" type="revolute">
    <origin xyz="0.587362 -0.0614058 -0.009" rpy="-0 -0 -0.00454143"/>
    <parent link="part_22"/>
    <child link="part_33"/>
    <axis xyz="0 0 1"/>
    <limit effort="10" velocity="10" lower="-3.141592653589793" upper="3.141592653589793"/>
  </joint>
  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
  <joint name="gantry_base" type="revolute">
    <origin xyz="0.0166 -0 0.065" rpy="-1.5708 0.00227071 1.5708"/>
    <parent link="part_40"/>
    <child link="part_22"/>
    <axis xyz="0 0 1"/>
    <limit effort="10" velocity="10" lower="-3.141592653589793" upper="3.141592653589793"/>
  </joint>
  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
  <joint name="swivel" type="revolute">
    <origin xyz="-0 0 0.16733" rpy="0 0 -0"/>
    <parent link="tophalfbase"/>
    <child link="part_40"/>
    <axis xyz="0 0 1"/>
    <limit effort="10" velocity="10" lower="-3.141592653589793" upper="3.141592653589793"/>
  </joint>
</robot>

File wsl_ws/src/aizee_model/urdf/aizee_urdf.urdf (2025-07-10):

<?xml version="1.0" encoding="utf-8"?>
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
<robot name="aizee_urdf">
  <link name="base_link">
    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
  </link>
  <link name="fr_wheel_link">
    <inertial>
      <origin xyz="-5.46627908770692E-08 -0.0186624897526542 -3.37595906091392E-09" rpy="0 0 0" />
      <mass value="0.426146379184826" />
      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
    </inertial>
    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
  </link>
  <joint name="fr_wheel_joint" type="continuous">
    <origin xyz="-0.164400000012016 0.18552749994085 0.0449999999998704" rpy="3.14159265358979 0 0" />
    <parent link="base_link" />
    <child link="fr_wheel_link" />
    <axis xyz="0 1 0" />
  </joint>
  <link name="fl_wheel_link">
    <inertial>
      <origin xyz="-5.45316413413932E-08 -0.0186624897523085 -3.17734610844056E-09" rpy="0 0 0" />
      <mass value="0.426146379160631" />
      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
    </inertial>
    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
  </link>
  <joint name="fl_wheel_joint" type="continuous">
    <origin xyz="-0.164400000012017 -0.182527499940847 0.0449999999998682" rpy="-3.14159265358979 0.937838269683351 3.14159265358979" />
    <parent link="base_link" />
    <child link="fl_wheel_link" />
    <axis xyz="0 1 0" />
  </joint>
  <link name="br_wheel_link">
    <inertial>
      <origin xyz="-5.46627909325803E-08 0.0186625103656381 -3.37595910948618E-09" rpy="0 0 0" />
      <mass value="0.426146379184826" />
      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
    </inertial>
    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
  </link>
  <joint name="br_wheel_joint" type="continuous">
    <origin xyz="0.164799999987984 0.182527499940852 0.0449999999998817" rpy="0 0 0" />
    <parent link="base_link" />
    <child link="br_wheel_link" />
    <axis xyz="0 1 0" />
  </joint>
  <link name="bl_wheel_link">
    <inertial>
      <origin xyz="-5.46069843510022E-08 0.0186625103671857 -3.44144951772152E-09" rpy="0 0 0" />
      <mass value="0.426146379308016" />
      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
    </inertial>
    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
  </link>
  <joint name="bl_wheel_joint" type="continuous">
    <origin xyz="0.164799999987983 -0.182527499940849 0.044999999999874" rpy="3.14159265358979 -0.0959172982254348 0" />
    <parent link="base_link" />
    <child link="bl_wheel_link" />
    <axis xyz="0 1 0" />
  </joint>
  <link name="gantry_swivel_link">
    <inertial>
      <origin xyz="-0.00465556417346933 0.47244048275071 0.00644612717972496" rpy="0 0 0" />
      <mass value="4.13256157024676" />
      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
    </inertial>
    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
  </link>
  <joint name="gantry_swivel_joint" type="continuous">
    <origin xyz="-0.00171500001182112 0 0.0449999999986612" rpy="1.57079632679467 0 2.20130112028515" />
    <parent link="base_link" />
    <child link="gantry_swivel_link" />
    <axis xyz="0 1 0" />
    <limit lower="-3.14" upper="3.14" effort="1" velocity="1" />
  </joint>
  <link name="gantry_base_link">
    <inertial>
      <origin xyz="-0.0889206626308974 0.00183063032907627 -0.00190283858000342" rpy="0 0 0" />
      <mass value="2.87751988332943" />
      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
    </inertial>
    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
  </link>
  <joint name="gantry_base_joint" type="prismatic">
    <origin xyz="0.0748880019266167 1.25057075528059 -0.106672907010273" rpy="0 0.940291533304643 0" />
    <parent link="gantry_swivel_link" />
    <child link="gantry_base_link" />
    <axis xyz="0 1 0" />
    <limit lower="-3.14" upper="3.14" effort="0" velocity="0" />
  </joint>
  <link name="head_swivel_link">
    <inertial>
      <origin xyz="-0.0317534999757447 0.0389950791481321 -0.000234878143316077" rpy="0 0 0" />
      <mass value="0.0645692908984822" />
      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
    </inertial>
    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
  </link>
  <joint name="head_swivel_joint" type="continuous">
    <origin xyz="0.0134984733922502 0.0590514537320603 0.00240000000046037" rpy="-3.13556944999228 0 -1.57079632679489" />
    <parent link="gantry_base_link" />
    <child link="head_swivel_link" />
    <axis xyz="1 0 0" />
    <limit lower="-3.14" upper="3.14" effort="1" velocity="1" />
  </joint>
  <link name="head_tilt_link">
    <inertial>
      <origin xyz="0.000344345851994721 0.0064615864545485 -2.06908995458513E-05" rpy="0 0 0" />
      <mass value="0.0805110064262411" />
      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
    </inertial>
    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
  </link>
  <joint name="head_tilt_joint" type="continuous">
    <origin xyz="-0.0428400156095763 0 0" rpy="0 -0.0307989676412341 0.000185569376448724" />
    <parent link="head_swivel_link" />
    <child link="head_tilt_link" />
    <axis xyz="0 0.999981860564052 -0.0060231671782995" />
    <limit lower="-3.14" upper="3.14" effort="1" velocity="1" />
  </joint>
  <link name="head_pitch_link">
    <inertial>
      <origin xyz="-0.0378363465971917 -0.0127393114972805 -0.00216806542954933" rpy="0 0 0" />
      <mass value="0.113884247586373" />
      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
    </inertial>
    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
  </link>
  <joint name="head_pitch_joint" type="continuous">
    <origin xyz="-0.00715658863949598 0 0.000220485265825118" rpy="0.0301375093124696 -0.0107085179536229 1.06890143125903" />
    <parent link="head_tilt_link" />
    <child link="head_pitch_link" />
    <axis xyz="0.0307946572743629 0.00602031058358343 0.999507601243648" />
    <limit lower="-3.14" upper="3.14" effort="1" velocity="1" />
  </joint>
  <link name="left_shoulder_pitch_link">
    <inertial>
      <origin xyz="-0.00366625450710334 -0.0540212847619638 0.000196348311228389" rpy="0 0 0" />
      <mass value="0.224603058456901" />
      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
    </inertial>
    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
  </link>
  <joint name="left_shoulder_pitch_joint" type="continuous">
    <origin xyz="0.00190847339162745 -0.0183487092181731 -0.173009266509531" rpy="-1.5707963267949 0 1.6247704646502" />
    <parent link="gantry_base_link" />
    <child link="left_shoulder_pitch_link" />
    <axis xyz="0 -1 0" />
    <limit lower="-3.14" upper="3.14" effort="1" velocity="1" />
  </joint>
  <link name="left_upper_arm_link">
    <inertial>
      <origin xyz="-0.0766963883885792 0.0134039791436639 -0.000276321241977517" rpy="0 0 0" />
      <mass value="0.311240729701745" />
      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
    </inertial>
    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
  </link>
  <joint name="left_upper_arm_joint" type="continuous">
    <origin xyz="0 -0.0210000249999997 0" rpy="0.0081422452723712 -0.00061707146343348 0.151282779582159" />
    <parent link="left_shoulder_pitch_link" />
    <child link="left_upper_arm_link" />
    <axis xyz="-0.0539479353612052 0 -0.998543749802813" />
    <limit lower="-3.14" upper="3.14" effort="1" velocity="1" />
  </joint>
  <link name="left_upper_elbow_link">
    <inertial>
      <origin xyz="0.00639542080557087 0.0872573783842139 -0.00206860491854177" rpy="0 0 0" />
      <mass value="0.174638971803144" />
      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
    </inertial>
    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
  </link>
  <joint name="left_upper_elbow_joint" type="continuous">
    <origin xyz="-0.0862752361730879 0.0131904590673325 0.00456101284018645" rpy="1.72230140662095 1.51682218893959 3.1415926535897" />
    <parent link="left_upper_arm_link" />
    <child link="left_upper_elbow_link" />
    <axis xyz="0 -1 0" />
    <limit lower="-3.14" upper="3.14" effort="1" velocity="1" />
  </joint>
  <link name="left_lower_elbow_link">
    <inertial>
      <origin xyz="-0.0384012806454133 -0.00785859011357548 -0.00587888140572804" rpy="0 0 0" />
      <mass value="0.151902535776002" />
      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
    </inertial>
    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
  </link>
  <joint name="left_lower_elbow_joint" type="continuous">
    <origin xyz="0.0381999999999998 0.112403218450234 0" rpy="1.96400162440634 -0.0881271151701579 -1.59563952845257" />
    <parent link="left_upper_elbow_link" />
    <child link="left_lower_elbow_link" />
    <axis xyz="0.0880130878902615 0.920101163566549 -0.381664178517586" />
    <limit lower="-3.14" upper="3.14" effort="1" velocity="1" />
  </joint>
  <link name="left_forearm_link">
    <inertial>
      <origin xyz="-0.0881848451431847 0.004762090677078 -0.0158110196363526" rpy="0 0 0" />
      <mass value="0.133070486658893" />
      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
    </inertial>
    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
  </link>
  <joint name="left_forearm_joint" type="continuous">
    <origin xyz="-0.0269534702231413 -0.00214213478108545 -0.00613953045680382" rpy="-2.03700008275405 -0.274733744913231 -0.191545917444499" />
    <parent link="left_lower_elbow_link" />
    <child link="left_forearm_link" />
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

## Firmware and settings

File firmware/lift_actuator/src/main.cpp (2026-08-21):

// ============================================================================
// Vertical Gantry Actuator (Minerva `lift` joint) — firmware
// ============================================================================
// Board : Elegoo Uno R3 (ATmega328P, 16 MHz)
// CAN   : Inland/Seeed-style MCP2515 shield (16 MHz crystal -> 1 Mbps OK)
// Enc   : AS5600 magnetic encoder on I2C (A4=SDA, A5=SCL), multi-turn tracked
// Motor : IKEA desk-leg 12 VDC column (non-backdrivable) via DROK L298 H-bridge
//
// It emulates a ROBSTRIDE motor on the AIZEE CAN chain (see include/protocol.h)
// so rust/motor_control drives it as an ordinary joint. We run our own position
// PID in encoder counts and ignore the MIT Kp/Kd/torque fields.
//
// Position pipeline:
//   AS5600 multi-turn counts  --(LIFT_RAD_PER_COUNT)-->  pseudo-radians (±4π)
//   which is what we report/accept over CAN. The meters<->rad mapping for the
//   policy lives in the Minerva command layer (a linear axis needs it anyway).
//
// Boot behaviour: STALL-HOME to the bottom hard stop (sets absolute zero), THEN
// start answering CAN. The AS5600 is single-turn absolute, so turn-count — and
// thus absolute height — is lost on every power cycle and must be re-homed.
// Enable the arm on the Jetson AFTER the leg's boot-home LED settles.
// ============================================================================

#include <Arduino.h>
#include <SPI.h>
#include <mcp_can.h>
#include <Wire.h>
#include "AS5600.h"
#include "protocol.h"

// ---------------------------------------------------------------------------
// Node identity — must match the `can_id` given to this joint in the Minerva
// hardware yaml (as `type: ROBSTRIDE02`). Pick an id unused by other motors.
// ---------------------------------------------------------------------------
static const uint8_t LIFT_CAN_ID = 0x11;   // 17 — Minerva joint index 16 (+1)

// ---------------------------------------------------------------------------
// Pins  (Uno + MCP2515 shield leaves A4/A5 for I2C and D3-D8 mostly free)
// ---------------------------------------------------------------------------
static const uint8_t PIN_CAN_CS = 9;   // Seeed-style shields = D9; some = D10
static const uint8_t PIN_ENA    = 3;   // L298 ENA — PWM speed (must be a PWM pin)
static const uint8_t PIN_IN1    = 4;   // L298 IN1 — direction
static const uint8_t PIN_IN2    = 7;   // L298 IN2 — direction

// ---------------------------------------------------------------------------
// Calibration & tuning  (CALIBRATE marks values to measure on the bench)
// ---------------------------------------------------------------------------
// CALIBRATE: pick so the full mechanical stroke maps to < 4π (12.566) rad with
// margin. Reported pos(rad) = counts * LIFT_RAD_PER_COUNT (4096 counts/rev).
static const float LIFT_RAD_PER_COUNT = 6.0e-5f;
// CALIBRATE: encoder counts at the TOP hard stop — firmware safety backstop.
static const long  LIFT_MAX_COUNTS    = 180000L;

static const uint8_t LIFT_INVERT = 0;  // set 1 if "up" drive DECREASES counts

// Position PID (P + light I). Output is PWM counts (0-255).
static const float KP_PWM_PER_COUNT = 0.02f;
static const int   DEADBAND_COUNTS  = 40;    // within this, coast (leg self-holds)
static const int   MIN_PWM          = 55;    // overcome stiction
static const int   MAX_PWM          = 220;   // cap speed (desk legs are slow)

// Stall homing
static const int          HOMING_PWM        = 110;   // drive toward bottom
static const long         STALL_EPS_COUNTS  = 8;     // "not moving" threshold
static const unsigned long STALL_WINDOW_MS  = 350;   // motionless this long = stop
static const unsigned long HOMING_TIMEOUT_MS = 30000;

// Command watchdog — mirror motor_control's 0.5 s watchdog_timeout.
static const unsigned long WATCHDOG_MS = 500;
// Feedback heartbeat: reply per control frame, plus this floor so telemetry
// stays fresh if control frames are sparse.
static const unsigned long FEEDBACK_MS = 20;

// ---------------------------------------------------------------------------
// State
// ---------------------------------------------------------------------------
MCP_CAN CAN(PIN_CAN_CS);
AS5600  encoder;

static bool  homed        = false;
static bool  enabled      = false;      // Robstride Run/Reset mirror
static long  cur_counts   = 0;          // AS5600 cumulative (0 = bottom stop)
static long  target_counts = 0;
static unsigned long last_cmd_ms      = 0;
static unsigned long last_feedback_ms = 0;

// ---------------------------------------------------------------------------
// Motor output — DROK L298 (ENA=PWM, IN1/IN2=direction). Positive pwm must
// raise the leg (increase counts); LIFT_INVERT flips it. Coast at pwm==0: the
// leg is non-backdrivable, so a coasting column holds its height with no current.
// ---------------------------------------------------------------------------
static void driveMotor(int pwm) {
    if (LIFT_INVERT) pwm = -pwm;
    if (pwm > 255) pwm = 255;
    if (pwm < -255) pwm = -255;

    if (pwm > 0) {            // up
        digitalWrite(PIN_IN1, HIGH);
        digitalWrite(PIN_IN2, LOW);
        analogWrite(PIN_ENA, pwm);
    } else if (pwm < 0) {     // down
        digitalWrite(PIN_IN1, LOW);
        digitalWrite(PIN_IN2, HIGH);
        analogWrite(PIN_ENA, -pwm);
    } else {                  // coast (holds mechanically)
        digitalWrite(PIN_IN1, LOW);
        digitalWrite(PIN_IN2, LOW);
        analogWrite(PIN_ENA, 0);
    }
}

// ---------------------------------------------------------------------------
// CAN feedback — emulate a Robstride telemetry frame at our current position.
// ---------------------------------------------------------------------------
static void sendFeedback(uint8_t mode) {
    uint16_t pos = rs_encode_pos((float)cur_counts * LIFT_RAD_PER_COUNT);
    uint8_t buf[8];
    buf[0] = pos >> 8;             buf[1] = pos & 0xFF;             // position
    buf[2] = RS_SIGNED_ZERO >> 8;  buf[3] = RS_SIGNED_ZERO & 0xFF;  // velocity ~0
    buf[4] = RS_SIGNED_ZERO >> 8;  buf[5] = RS_SIGNED_ZERO & 0xFF;  // torque   ~0
    uint16_t temp = 250;                                            // 25.0°C ×10
    buf[6] = temp >> 8;            buf[7] = temp & 0xFF;
    CAN.sendMsgBuf(rs_feedback_arb(LIFT_CAN_ID, mode, 0), 1 /*ext*/, 8, buf);
    last_feedback_ms = millis();
}

// ---------------------------------------------------------------------------
// Stall homing: drive down until the encoder stops changing, then zero.
// ---------------------------------------------------------------------------
static void homeStallToBottom() {
    homed = false;
    long last_seen   = encoder.getCumulativePosition();
    unsigned long t_still = millis();
    unsigned long t_start = millis();

    driveMotor(-HOMING_PWM);   // toward the bottom hard stop
    while (millis() - t_start < HOMING_TIMEOUT_MS) {
        long now = encoder.getCumulativePosition();
        if (labs(now - last_seen) > STALL_EPS_COUNTS) {
            last_seen = now;
            t_still = millis();          // still moving — reset the still-timer
        } else if (millis() - t_still > STALL_WINDOW_MS) {
            break;                        // motionless long enough → hard stop
        }
        delay(5);
    }
    driveMotor(0);
    delay(150);                           // let it settle against the stop
    encoder.resetCumulativePosition(0);   // this position is absolute zero
    cur_counts = 0;
    target_counts = 0;
    homed = true;
}

// ---------------------------------------------------------------------------
// Handle one received CAN frame if it's addressed to us.
// ---------------------------------------------------------------------------
static void handleCanFrame(uint32_t arb, uint8_t len, const uint8_t* data) {
    if (rs_cmd_motor(arb) != LIFT_CAN_ID) return;   // not ours

    switch (rs_msg_type(arb)) {
        case RS_MSG_ENABLE:
            enabled = true;
            last_cmd_ms = millis();
            sendFeedback(RS_MODE_RUN);   // the enable poll waits for this
            break;

        case RS_MSG_DISABLE:
            enabled = false;
            driveMotor(0);
            sendFeedback(RS_MODE_RESET);
            break;

        case RS_MSG_CONTROL: {
            last_cmd_ms = millis();
            if (len >= 2) {
                uint16_t pos_raw = ((uint16_t)data[0] << 8) | data[1];
                float pos_rad = rs_decode_pos(pos_raw);
                long t = (long)(pos_rad / LIFT_RAD_PER_COUNT);
                if (t < 0) t = 0;                          // 0 = bottom
                if (t > LIFT_MAX_COUNTS) t = LIFT_MAX_COUNTS;
                target_counts = t;
            }
            sendFeedback(enabled ? RS_MODE_RUN : RS_MODE_RESET);  // reply per control
            break;
        }

        case RS_MSG_ZEROPOS:
            // motor_control's mech_zero: re-home to re-establish absolute zero.
            driveMotor(0);
            homeStallToBottom();
            sendFeedback(enabled ? RS_MODE_RUN : RS_MODE_RESET);
            break;

        default:
            // ReadParam/WriteParam/SaveConfig/VBUS queries — not needed for the
            // enable handshake; ignore. (VBUS round-robin is fire-and-forget.)
            break;
    }
}

static void serviceCan() {
    uint32_t rxId;
    uint8_t  ext, len, buf[8];
    while (CAN.checkReceive() == CAN_MSGAVAIL) {
        if (CAN.readMsgBuf(&rxId, &ext, &len, buf) != CAN_OK) break;
        if (!ext) continue;                 // Robstride uses extended ids only
        handleCanFrame(rxId & 0x1FFFFFFF, len, buf);
    }
}

// ---------------------------------------------------------------------------
// Position control step (P-controller; leg is slow so P is plenty).
// ---------------------------------------------------------------------------
static void runControl() {
    long err = target_counts - cur_counts;
    if (labs(err) <= DEADBAND_COUNTS) { driveMotor(0); return; }

    int pwm = (int)(KP_PWM_PER_COUNT * (float)err);
    if (pwm > 0 && pwm < MIN_PWM)  pwm = MIN_PWM;
    if (pwm < 0 && pwm > -MIN_PWM) pwm = -MIN_PWM;
    if (pwm >  MAX_PWM) pwm =  MAX_PWM;
    if (pwm < -MAX_PWM) pwm = -MAX_PWM;
    driveMotor(pwm);
}

void setup() {
    Serial.begin(115200);

    pinMode(PIN_ENA, OUTPUT);
    pinMode(PIN_IN1, OUTPUT);
    pinMode(PIN_IN2, OUTPUT);
    driveMotor(0);

    Wire.begin();
    encoder.begin();
    if (!encoder.isConnected()) {
        Serial.println(F("[LIFT] AS5600 not found — check I2C wiring/magnet"));
    }

    // 1 Mbps to match the AIZEE CAN chain; 16 MHz crystal on the shield.
    while (CAN.begin(MCP_ANY, CAN_1000KBPS, MCP_16MHZ) != CAN_OK) {
        Serial.println(F("[LIFT] MCP2515 init failed — retrying"));
        delay(500);
    }
    CAN.setMode(MCP_NORMAL);
    Serial.print(F("[LIFT] CAN up, id=0x"));
    Serial.println(LIFT_CAN_ID, HEX);

    homeStallToBottom();   // establish absolute zero before answering enable
    Serial.println(F("[LIFT] homed — ready"));
    last_cmd_ms = millis();
}

void loop() {
    cur_counts = encoder.getCumulativePosition();  // call often: tracks wraps

    serviceCan();

    // Command watchdog: on dropout, stop at the current height and coast (the
    // non-backdrivable column holds). Stay "enabled" so we resume cleanly.
    if (enabled && (millis() - last_cmd_ms > WATCHDOG_MS)) {
        target_counts = cur_counts;
    }

    if (enabled && homed) runControl();
    else                  driveMotor(0);

    if (enabled && (millis() - last_feedback_ms > FEEDBACK_MS)) {
        sendFeedback(RS_MODE_RUN);
    }
}

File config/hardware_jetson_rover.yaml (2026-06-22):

# AIZEE Hardware Configuration - Jetson (rover wheels + swivel + 6-DoF gantry)
# History:
#   2026-05-30: arm separated from rover — left_wheel / right_wheel removed
#               because motor_control hung during CAN init enumerating the
#               absent wheel motors (Tufty yellow, no telem on :5556).
#   2026-06-21: wheels re-added (drive controls back). NOTE: both wheel motors
#               MUST be physically present on the CAN bus or motor_control will
#               wedge during init again — only deploy this with wheels wired.
# File name kept as "rover" so the systemd unit (aizee-motor-control-rover)
# and deploy scripts don't need re-wiring.

motors:
  # Drive wheels - ROBSTRIDE 04 Series
  wheels:
    - id: left_wheel
      can_id: 0x02
      type: ROBSTRIDE04
      max_velocity: 10.0  # rad/s
      max_torque: 12.0    # Nm

    - id: right_wheel
      can_id: 0x04
      type: ROBSTRIDE04
      max_velocity: 10.0
      max_torque: 12.0

  # Base swivel - ROBSTRIDE 03 Series
  swivel:
    id: swivel
    can_id: 0x03
    type: ROBSTRIDE03
    min_position: -15.0  # ±4π encoder range is ±12.566; ±15 gives headroom
    max_position: 15.0   # Teleop enforces relative travel via swivel_position
    max_velocity: 5.0
    max_torque: 6.0

  # Gantry arm - 6DoF
  # Position limits from robstride_calibration.json + safety margin.
  # max_torque limits feedforward torque; PD torque is bounded by MIT encoding.
  arm:
    - id: gantry_base
      can_id: 0x05
      type: ROBSTRIDE04
      min_position: -2.5   # Physical range ~[-1.88, 0.02] + margin
      max_position: 0.5
      max_velocity: 10.0
      max_torque: 60.0    # RS04 peak=120Nm; gravity+PD needs headroom

    - id: gantry_mid
      can_id: 0x06
      type: ROBSTRIDE03
      min_position: -0.5   # Physical range ~[-0.01, 2.61] + margin
      max_position: 3.2
      max_velocity: 5.0
      max_torque: 40.0    # RS03 peak=60Nm; ~22Nm gravity at full extension

    - id: gantry_end
      can_id: 0x07
      type: ROBSTRIDE02
      min_position: -4.5   # Physical range ~[-3.95, 0.01] + margin
      max_position: 0.5
      max_velocity: 10.0
      max_torque: 12.0    # RS02 peak=17Nm

    - id: wrist_pitch
      can_id: 0x08
      type: ROBSTRIDE02
      min_position: -3.5   # Physical range ~[-3.27, 3.21] + margin
      max_position: 3.5
      max_velocity: 10.0
      max_torque: 12.0    # RS02 peak=17Nm

    - id: wrist_roll
      can_id: 0x09
      type: ROBSTRIDE00
      min_position: -1.0   # Physical range ~[-0.38, 2.57] + margin
      max_position: 3.2
      max_velocity: 30.0
      max_torque: 1.5     # RS00 peak=2Nm, nominal=0.5Nm

    - id: gripper
      can_id: 0x0A
      type: ROBSTRIDE00
      min_position: -0.5   # Physical range ~[0.08, 7.30] but mechanism is much smaller
      max_position: 5.0    # Conservative: real gripper likely <2 rad travel
      max_velocity: 30.0
      max_torque: 1.5     # RS00 peak=2Nm, nominal=0.5Nm

# Control loop parameters
control:
  arm_frequency: 400.0   # Hz - limited by CAN bus: 6 motors × ~280µs round-trip = 1680µs/cycle
  base_frequency: 100.0  # Hz - wheels + swivel
  telemetry_rate: 50.0   # Hz - published motor states
  watchdog_timeout: 0.5  # seconds - hold position if no command received (500ms tolerates WiFi jitter)

# CAN bus configuration
can:
  interface: can1

# LiDAR sensors - RPLiDAR A1M8
lidars:
  - id: lidar_front
    device: /dev/rplidar_front  # Udev symlink (see config/udev/99-rplidar.rules)
    scan_mode: standard

  - id: lidar_back
    device: /dev/rplidar_back   # Udev symlink (see config/udev/99-rplidar.rules)
    scan_mode: standard

# UPS Power Module - Waveshare UPS Power Module (C)
ups:
  enabled: true
  i2c_bus: 7              # I2C bus number (Jetson Orin Nano default)
  i2c_addr: 0x41          # INA219 I2C address
  update_rate: 1.0        # Hz - publishing rate
  battery_chemistry: "lipo_3s"  # 3S LiPo (11.1V nominal)
  voltage_full: 12.6      # Fully charged (3 × 4.2V)
  voltage_nominal: 11.1   # Nominal (3 × 3.7V)
  voltage_warning: 10.5   # Warning threshold (3 × 3.5V)
  voltage_critical: 9.9   # Critical threshold (3 × 3.3V)
  voltage_min: 9.0        # Absolute minimum (3 × 3.0V)

# Tufty2040 Status Display — Raspberry Pi Pico connected via USB CDC
display:
  enabled: true
  serial_port: "/dev/tufty_display"   # Udev symlink (see config/udev/99-aizee-display.rules)
  baud_rate: 115200
  update_rate: 2.0                     # Hz — display refresh rate
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

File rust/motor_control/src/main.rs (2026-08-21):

// AIZEE Motor Control - Main Control Loop

mod motor;
mod robstride;

use anyhow::{Context, Result};
use comms::{
    ArmJointsPayload, CommandMessage, CommandSubscriber, DrivePayload, MotorTelemetry,
    TelemetryMessage, TelemetryPublisher,
};
use motor::{Motor, MotorConfig, MotorGroup, MotorState};
use robstride::MotorModel;
use socketcan::{CanSocket, EmbeddedFrame, Frame, Socket, SocketOptions};
use std::cell::RefCell;
use std::collections::HashMap;
use std::process::Command;
use std::time::{Duration, Instant};
use tokio::time::interval;
use tracing::{debug, error, info, warn};

#[derive(Debug, Clone, serde::Deserialize)]
struct Config {
    motors: MotorsConfig,
    control: ControlConfig,
    can: CanConfig,
    network: NetworkConfig,
}

#[derive(Debug, Clone, serde::Deserialize)]
struct MotorsConfig {
    wheels: Vec<MotorConfigYaml>,
    swivel: MotorConfigYaml,
    arm: Vec<MotorConfigYaml>,
}

#[derive(Debug, Clone, serde::Deserialize)]
struct MotorConfigYaml {
    id: String,
    can_id: u8,
    #[serde(default = "default_can_bus")]
    can_bus: String,  // Optional, defaults to "can1" for backward compatibility
    #[serde(rename = "type")]
    motor_type: String,
    #[serde(default)]
    min_position: Option<f32>,
    #[serde(default)]
    max_position: Option<f32>,
    max_velocity: f32,
    max_torque: f32,
}

fn default_can_bus() -> String {
    "can1".to_string()
}

#[derive(Debug, Clone, serde::Deserialize)]
struct ControlConfig {
    arm_frequency: f32,
    base_frequency: f32,
    telemetry_rate: f32,
    watchdog_timeout: f32,
}

#[derive(Debug, Clone, serde::Deserialize)]
struct CanConfig {
    #[serde(default)]
    interface: String,  // Legacy single interface (deprecated)
    #[serde(default)]
    interfaces: HashMap<String, String>,  // New: map of bus name -> interface name
}

#[derive(Debug, Clone, serde::Deserialize)]
struct NetworkConfig {
    #[serde(alias = "jetson")]  // Backward compatibility
    device: DeviceConfig,
}

#[derive(Debug, Clone, serde::Deserialize)]
struct DeviceConfig {
    #[serde(default)]
    ip: String,
    #[serde(default)]
    hostname: String,
    zmq: ZmqConfig,
}

#[derive(Debug, Clone, serde::Deserialize)]
struct ZmqConfig {
    command_sub: String,
    telemetry_pub: String,
}

fn load_config() -> Result<Config> {
    let config_path = std::env::var("AIZEE_CONFIG").unwrap_or_else(|_| "config/hardware.yaml".to_string());
    let config_str = std::fs::read_to_string(&config_path)
        .with_context(|| format!("Failed to read config from {}", config_path))?;
    let config: Config = serde_yaml::from_str(&config_str)?;
    Ok(config)
}

fn parse_motor_model(type_str: &str) -> MotorModel {
    match type_str {
        "ROBSTRIDE04" => MotorModel::Model04,
        "ROBSTRIDE03" => MotorModel::Model03,
        "ROBSTRIDE02" => MotorModel::Model02,
        "ROBSTRIDE00" => MotorModel::Model00,
        _ => {
            warn!("Unknown motor type {}, defaulting to Model03", type_str);
            MotorModel::Model03
        }
    }
}

fn yaml_to_motor_config(yaml: &MotorConfigYaml) -> MotorConfig {
    MotorConfig {
        id: yaml.id.clone(),
        can_id: yaml.can_id,
        can_bus: yaml.can_bus.clone(),
        model: parse_motor_model(&yaml.motor_type),
        min_position: yaml.min_position,
        max_position: yaml.max_position,
        max_velocity: yaml.max_velocity,
        max_torque: yaml.max_torque,
    }
}

struct ControlSystem {
    can_sockets: HashMap<String, CanSocket>,  // bus_name -> socket
    can_interfaces: HashMap<String, String>,  // bus_name -> interface_name (for socket recovery)
    base_group: MotorGroup,
    arm_group: MotorGroup,
    command_sub: CommandSubscriber,
    telemetry_pub: TelemetryPublisher,
    motor_id_map: HashMap<String, u8>, // motor_id -> can_id
    motor_bus_map: HashMap<String, String>, // motor_id -> can_bus
    emergency_stop: bool,
    last_base_control: Instant,
    control_tick: u64,
    battery_voltage: Option<f32>, // Avg VBUS across fresh per-motor readings
    last_vbus_request: Instant,   // Track when we last requested VBUS
    last_battery_voltage_update: Option<Instant>, // Track freshness of battery reading
    // Per-motor VBUS readings (CAN id -> (volts, when received)).  Robstrides
    // each report their own input voltage; we round-robin queries across
    // ALL motors and average the fresh values for the published
    // battery_voltage.  Used to be single-source from base_group.first(),
    // which broke when the wheels were retired (2026-05-30).
    motor_vbus: HashMap<u8, (f32, Instant)>,
    vbus_query_idx: usize,        // Round-robin cursor over all motors
    dropped_frames: RefCell<HashMap<String, u64>>, // Track dropped frames per CAN bus
    last_buffer_warning: RefCell<HashMap<String, Instant>>, // Rate-limit buffer warnings
    consecutive_tx_errors: RefCell<HashMap<String, u32>>, // Track consecutive errors for recovery
    last_error_log: Instant, // Rate-limit "group has errors" log flood
    last_hold_log: Instant,  // Rate-limit "command timeout hold" log
    last_socket_recovery: Instant, // Rate-limit socket recovery to prevent storm
    can_recovery_level: HashMap<String, u32>, // Current recovery escalation level per bus (0=socket, 1=link, 2=exit)
    can_recovery_attempts: HashMap<String, u32>, // Attempts at current level per bus
    total_recoveries: u32, // Total recovery attempts across all levels (exit at 10)
    last_link_recovery: Instant, // Rate-limit link-level recovery
}
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

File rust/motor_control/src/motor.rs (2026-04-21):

// Motor state management and control

use crate::robstride::{MotorError, MotorFeedback, MotorMode, MotorModel};
use anyhow::{anyhow, Result};
use std::time::{Duration, Instant};

/// Motor state machine
#[derive(Debug, Clone, Copy, PartialEq, Eq)]
pub enum MotorState {
    Idle,
    Enabling,
    Enabled,
    Running,
    Error,
    Disabled,
}

impl MotorState {
    pub fn as_str(&self) -> &'static str {
        match self {
            MotorState::Idle => "idle",
            MotorState::Enabling => "enabling",
            MotorState::Enabled => "enabled",
            MotorState::Running => "running",
            MotorState::Error => "error",
            MotorState::Disabled => "disabled",
        }
    }
}

/// Structured fault information for diagnostics and telemetry
#[derive(Debug, Clone)]
pub struct FaultInfo {
    pub error: MotorError,
    pub mode_at_fault: MotorMode,
    pub recovery_attempts: u32,
}

/// Motor configuration from hardware.yaml
#[derive(Debug, Clone)]
pub struct MotorConfig {
    pub id: String,
    pub can_id: u8,
    pub can_bus: String,  // CAN bus name (e.g., "can1", "can2")
    pub model: MotorModel,
    pub min_position: Option<f32>,
    pub max_position: Option<f32>,
    pub max_velocity: f32,
    pub max_torque: f32,
}

/// Motor controller with state tracking
pub struct Motor {
    pub config: MotorConfig,
    pub state: MotorState,
    pub feedback: Option<MotorFeedback>,
    pub last_command_time: Instant,
    pub command_timeout: Duration,
    pub target_position: f32,
    pub target_velocity: f32,
    pub target_torque: f32,
    pub kp: f32,
    pub kd: f32,
    pub consecutive_errors: u32,
    pub position_initialized: bool,
    pub fault_info: Option<FaultInfo>,
    pub last_feedback_time: Instant,
}

impl Motor {
    pub fn new(config: MotorConfig, command_timeout: Duration) -> Self {
        Self {
            config,
            state: MotorState::Idle,
            feedback: None,
            last_command_time: Instant::now(),
            command_timeout,
            target_position: 0.0,
            target_velocity: 0.0,
            target_torque: 0.0,
            kp: 0.0,
            kd: 0.0,
            consecutive_errors: 0,
            position_initialized: false,
            fault_info: None,
            last_feedback_time: Instant::now(),
        }
    }

    /// Update motor state with new feedback
    pub fn update_feedback(&mut self, feedback: MotorFeedback) {
        self.last_feedback_time = Instant::now();

        // Mode transition detection: Run → Reset means the motor faulted
        // Only detect faults when motor is expected to be active (Enabled/Running)
        if let Some(prev) = &self.feedback {
            if prev.mode == MotorMode::Run && feedback.mode == MotorMode::Reset
                && matches!(self.state, MotorState::Enabled | MotorState::Running)
            {
                if self.state != MotorState::Error {
                    tracing::warn!(
                        "Motor {} [0x{:02X}] mode transition Run→Reset (hardware fault): \
                         undervolt={} overcurrent={} overtemp={} mag_enc={} hall_enc={} uncal={} \
                         pos={:.3} vel={:.3} torque={:.3} temp={:.1}°C",
                        self.config.id,
                        self.config.can_id,
                        feedback.error.undervoltage,
                        feedback.error.overcurrent,
                        feedback.error.overtemp,
                        feedback.error.magnetic_encoding_fault,
                        feedback.error.hall_encoding_fault,
                        feedback.error.uncalibrated,
                        feedback.position,
                        feedback.velocity,
                        feedback.torque,
                        feedback.temperature,
                    );
                    self.state = MotorState::Error;
                    self.fault_info = Some(FaultInfo {
                        error: feedback.error,
                        mode_at_fault: MotorMode::Run,
                        recovery_attempts: 0,
                    });
                }
            }
        }

        // Check for errors in feedback
        if feedback.error.has_error() {
            self.consecutive_errors += 1;
            if self.consecutive_errors >= 10 {
                // Only enter Error state after sustained errors (10 consecutive frames)
                if self.state != MotorState::Error {
                    tracing::warn!(
                        "Motor {} [0x{:02X}] FAULT after {} consecutive errors: \
                         undervolt={} overcurrent={} overtemp={} mag_enc={} hall_enc={} uncal={} \
                         mode={:?} pos={:.3} vel={:.3} torque={:.3} temp={:.1}°C",
                        self.config.id,
                        self.config.can_id,
                        self.consecutive_errors,
                        feedback.error.undervoltage,
                        feedback.error.overcurrent,
                        feedback.error.overtemp,
                        feedback.error.magnetic_encoding_fault,
                        feedback.error.hall_encoding_fault,
                        feedback.error.uncalibrated,
                        feedback.mode,
                        feedback.position,
                        feedback.velocity,
                        feedback.torque,
                        feedback.temperature,
                    );
                    self.state = MotorState::Error;
                    self.fault_info = Some(FaultInfo {
                        error: feedback.error,
                        mode_at_fault: feedback.mode,
                        recovery_attempts: 0,
                    });
                }
            } else {
                tracing::debug!(
                    "Motor {} transient error ({}/10): {:?}",
                    self.config.id,
                    self.consecutive_errors,
                    feedback.error
                );
            }
        } else {
            // Clear error counter on good feedback
            if self.consecutive_errors > 0 {
                tracing::debug!(
                    "Motor {} error cleared after {} bad frames",
                    self.config.id,
                    self.consecutive_errors
                );
            }
            self.consecutive_errors = 0;
        }

        self.feedback = Some(feedback);
    }
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

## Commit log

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2025-07-10 Moveit servo working, TF links are off, preventing good kinematics for servo.
    [aizee_model.ros2_control.xacro, aizee_model.urdf, aizee_model.urdf.xacro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]
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2026-02-06 Restructure repository for new software stack architecture
    Complete overhaul of AIZEE project structure to support modular robotics software stack with Rust motor control, Python teleop, and distributed camera nodes.
    Changes:
    - Remove old ROS workspace and documentation
    - Add new directory structure: rust/, python/, urdf/, config/, logs/, docs/
    - Create Rust workspace with motor_control, comms, and bindings packages
    - Add comprehensive hardware.yaml config (6 motors: 3 base, 3-DOF arm)
    - Define 8-week phased implementation roadmap in docs/PHASES.md
    - Add MIT license and updated README with system architecture
    - Configure Python dependencies for ZeroMQ, Rerun, RealSense
    Hardware configurati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
    [aizee_model.csv, aizee_model.ros2_control.xacro, aizee_model.urdf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]
2026-02-07 Fix ROBSTRIDE CAN protocol: correct frame layout and scaling tables
    The control frame was using MIT/Mini Cheetah 12-bit packed format, but
    ROBSTRIDE motors expect 4x 16-bit fields with torque in the CAN arb_id.
    Root cause: HOST_CAN_ID (0xAA) in arb_id bits 8-23 was interpreted by
    the motor as ~-120 Nm reverse torque feedforward on every control frame,
    causing the aggressive velocity transient at enable. Additionally, the
    12-bit packed data caused Kp/Kd/velocity values to bleed between fields.
    - build_control_frame: 4x u16 big-endian (pos, vel, kp, kd) in data,
    torque u16 in arb_id extra_data field (bits 8-23)
    - Model-specific scaling: RS-03 (vel ±50, torque ±60, Kp 0-5000,
    K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
    [hardware_two_motors.yaml]
2026-02-07 Add fault detection and recovery with structured telemetry
    Implement fault detection via hardware mode transition (Run→Reset) and
    CAN feedback heartbeat timeout (500ms). Add ClearFault command that
    performs disable/enable recovery cycle, TriggerFault for testing, and
    ClearEmergencyStop. Telemetry now includes motor state and hardware mode.
    Also includes ZMQ PUSH/PULL fix, config corrections, and test utilities.
    [hardware_two_motors.yaml]
2026-02-07 Add real-time teleop interface and fix motor enable feedback timeout
    Phase 2 teleop: curses-based terminal UI with Xbox controller and
    keyboard input (WASD drive, gamepad axes with deadzone/curve), ZMQ
    PUSH/SUB comms matching Rust protocol, 20Hz control loop, and
    config-driven setup. Tested end-to-end on Jetson with both motors.
    Fix enable_motor() feedback timeout race: reset last_feedback_time
    after the blocking enable sequence so check_safety() doesn't
    immediately trip the 500ms timeout on freshly enabled motors.
    [main.rs, teleop.py, teleop.yaml]
2026-02-07 Add Xbox controller support and fix drive control for smooth continuous motion
    Teleop improvements:
    - Windows gamepad support: create hidden SDL window for input processing
    - Auto-detect gamepad vs keyboard devices (skip Keychron etc)
    - Fix Xbox controller axis mapping (right stick Y=3, X=2)
    - Use pygame.event.get() on Windows for full event processing
    Motor control fix:
    - Switch base motors to pure velocity control (Kp=0, Kd=3.0)
    - Eliminates position wrapping at ±4π that caused violent snaps
    - Instant velocity response (no ramp-up delay from position integration)
    - Smooth continuous motion in both directions
    Tested with Xbox controller on Windows + ROBSTRIDE motors on Jetson.
    Co-Autho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
    [main.rs, teleop.py, teleop.yaml]
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2026-02-08 Add Jetson rover startup automation and fix teleop joystick controls
    Implements automatic rover module startup after reboot with systemd service,
    deployment scripts, and status checking utilities. Fixes gamepad axis mapping
    for correct directional control.
    - Add systemd service for automatic motor control startup on Jetson
    - Add deployment script for syncing code and building on Jetson
    - Add rover status check script for diagnostics
    - Add rover-only teleop config with corrected joystick axis mapping
    - Add comprehensive quick start guide for post-reboot operations
    The rover module now automatically starts on boot, configures CAN interface,
    and publishes telemetry without manual int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
    [teleop_rover_only.yaml]
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2026-02-09 Optimize camera streaming for low latency and smooth performance
    Major performance improvements to camera node and Rerun visualization bridge,
    reducing latency and improving frame rate stability from ~12-15 fps to ~20-25 fps.
    Camera Node (camera_node_opencv.py):
    - Reduce JPEG quality from 85% to 50% for faster compression and transmission
    - Switch from PIL to cv2.imencode() for 2-3x faster JPEG encoding
    - Optimize ZMQ publisher: SNDHWM=2 (drop old frames), 1MB send buffer
    - Add image orientation support (--flip-vertical, --flip-horizontal, --rotate-180)
    - Maintain stable 30 fps publishing rate on Raspberry Pi 4
    Rerun Bridge (rerun_bridge.py):
    - NEW: Complete rewrite with aggressive low-lat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
    [rerun_bridge.py]
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2026-02-10 feat(teleop): comprehensive optimization and critical bug fixes
    CRITICAL FIXES:
    - Fix exit hang bug with ZMQ_LINGER=0 (cleanup: 0.002s vs infinite hang)
    - Fix control feel and telemetry display for intuitive operation
    - Fix gamepad axis configuration consistency
    IMPROVEMENTS:
    - Add comprehensive logging infrastructure (teleop.log with configurable levels)
    - Add real-time connection health monitoring (rate, age, status indicators)
    - Optimize UI rendering with selective clearing (~70% CPU reduction)
    - Add robust error handling and graceful degradation on failures
    - Add telemetry rate tracking and stale connection detection
    - Standardize gamepad configuration across all config files
    TESTING: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
    [teleop.py, teleop_rover_only.yaml]
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2026-02-10 feat(lidar): complete Rerun visualization with smooth live streaming
    Implements real-time 3D point cloud visualization for RPLiDAR A1M8 sensors
    in Rerun viewer with smooth continuous playback.
    - Live streaming point clouds without timeline looping
    - Automatic wall-clock timeline for smooth playback
    - Color coding: magenta=lidar_back, cyan=lidar_front
    - Statistics tracking for scan rates
    - Command-line --lidar argument
    Integration status:
    - lidar_back: Fully operational (160 points/scan at 7 Hz)
    - lidar_front: Hardware OK, protocol sync issue (0-4 points/scan)
    - Systemd service installed and running
    - Udev rules configured for stable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
    [rerun_bridge.py]
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2026-02-11 Fix keyboard control smoothing in teleop
    - Replace curses event-based keyboard with pygame state-based keyboard
    - Eliminates timing hacks for keyboard repeat delay detection
    - Provides instant response on key press and release
    - Smooth acceleration/deceleration without drops or pauses
    - Add gamepad state display (axes, buttons, control mapping)
    - Fallback to curses for systems without pygame
    Fixes issues with:
    - Jerky keyboard input with pause-resume behavior
    - Delayed response on key release
    - Drop-to-zero during OS keyboard repeat delay
    [teleop.py]
2026-02-11 feat(motor_control): add dual-CAN bus support for rover and gantry motors
    Implement multi-CAN interface support to enable simultaneous control of rover
    motors on can1 (IDs 0x02-0x04) and gantry/arm motors on can2 (IDs 0x05-0x07).
    Key changes:
    - Add per-motor CAN bus assignment via `can_bus` field in MotorConfig
    - Refactor ControlSystem to use HashMap<String, CanSocket> for multiple buses
    - Add helper methods get_can_socket() and get_can_socket_by_bus() for routing
    - Update all CAN send/receive operations to route to correct bus
    - Support both legacy single-interface and new multi-interface configs
    - Add motor_bus_map to track motor_id -> can_bus mapping
    Configuration:
    - New config format: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
    [hardware_jetson_dual_can.yaml]
2026-02-11 fix: update Jetson IP address from 192.168.0.26 to 192.168.0.27
    Update all references to the Jetson IP address in documentation and
    configuration files to reflect the correct address.
    Files updated:
    - CLAUDE.md: Connection details, SCP/SSH commands, network topology
    - config/hardware_three_motors.yaml: Network configuration
    - config/hardware_two_motors.yaml: Network configuration
    [hardware_three_motors.yaml, hardware_two_motors.yaml]
2026-02-11 fix(config): correct CAN bus assignments for dual-CAN setup
    Swap CAN bus assignments to match actual hardware configuration:
    - Rover motors (left_wheel, swivel, right_wheel) on can2
    - Gantry motors (gantry_base, gantry_mid, gantry_end) on can1
    Previous config had them backwards, causing connection issues.
    [hardware_jetson_dual_can.yaml]
2026-02-11 Fix CAN buffer overflow causing gantry motor faults
    Problem: Gantry motors were faulting after a few seconds due to CAN transmit
    buffer overflow ("No buffer space available" errno 105). Default TX queue length
    of 10 frames was too small for 100Hz control rate with 3 motors (300 frames/sec).
    Solution:
    1. Increased CAN TX queue length from 10 to 1000 frames on both can1 and can2
    - Added setup_dual_can_jetson.sh script to configure queue lengths
    - Provides 3.3 seconds of buffer instead of 33ms
    2. Added robust error handling in Rust motor_control:
    - Created safe_write_frame() helper that catches ENOBUFS gracefully
    - Logs warnings instead of crashing control loops
    - Tracks droppe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
    [hardware_jetson_dual_can.yaml]
2026-02-12 fix: correct differential drive steering direction
    Swapped wheel CAN IDs and negated drive inputs to match physical motor
    orientation. Left wheel now on 0x04, right wheel on 0x02. Both linear
    and angular velocities negated to align controller input with robot motion.
    [hardware_jetson_dual_can.yaml]
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2026-02-17 fix(motor_control): fix CAN frame rate bug and add gs_usb adapter recovery
    Base motors were accidentally sent at arm frequency (1kHz) instead of
    base frequency (100Hz), flooding the CANable gs_usb adapter with 3x the
    intended frame rate and triggering its echo ID corruption bug. Split
    send_control_commands() into send_arm_commands() and send_base_commands()
    called from their respective control loop intervals.
    Also adds:
    - Treat all CAN write errors as recoverable (not just ENOBUFS)
    - Socket recovery after 50 consecutive TX errors (flushes stale URBs)
    - Inter-frame delay (200us) for USB adapter echo processing
    - can_watchdog.sh: monitors TX counter, auto-resets USB adapter on freeze
    - reset_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
    [find_motors.py, main.rs, query_motors.py]
2026-02-17 feat(gantry): add gantry_base motor and joystick control
    Add ROBSTRIDE04 gantry_base (CAN ID 0x05) to rover config as first arm
    motor. Map right joystick Y-axis to gantry base position with smoothed
    velocity control and feedforward for fluid motion.
    - Add gantry_base to hardware_jetson_rover.yaml arm section
    - Right stick Y controls gantry base position (velocity-integrated)
    - Smooth joystick rate ramping (fast accel, slow decel)
    - Velocity feedforward in arm_joints for better tracking
    - Clamp gantry positions to +/-pi soft limits in teleop
    - Accept arm_joints commands with more positions than motors (>=)
    - Fix gantry homing to work with partial motor set
    - Remove homing countdown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
    [hardware_jetson_rover.yaml]
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2026-02-17 feat(gantry): improve tuning and re-homing UX
    - Update gantry gains: kp=[5.0, 5.0, 2.0], kd=[0.2, 0.2, 0.1]
    - Allow H key to re-home gantry at any time (not just first time)
    - Reset smoothed joystick rate when homing to prevent drift
    [teleop.py, teleop.yaml]
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2026-02-18 feat(gantry): implement relative positioning with home offsets and fix initialization
    Fixes critical gantry initialization issues where motors would crash on enable
    and position limits prevented proper homing.
    **Relative Positioning System:**
    - Motor encoder positions are now stored as offsets
    - User sees relative positions (0.0 after homing)
    - Commands sent as: absolute = relative + offset
    - Allows motors to start at any encoder position
    **Auto-Homing on Enable:**
    - When motors first enable, reads actual encoder positions
    - Sets these as home offsets with relative position = 0.0
    - No movement on enable - motors stay in place
    - User can immediately control without pressing H
    **Wide Safety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
    [hardware_jetson_rover.yaml]
2026-02-18 feat(gantry): update control gains for improved performance
    Further tuning improvements after testing relative positioning system:
    **Updated Gains:**
    - gantry_base: Kp=75.0 (was 65.0), Kd=7.0 (was 5.5)
    - Increased stiffness and damping for better load bearing
    - gantry_mid: Kp=65.0 (was 5.0), Kd=5.5 (was 0.2)
    - Significantly increased stiffness for mid-joint stability
    - gantry_end: Kp=10.0, Kd=0.2 (unchanged)
    - Maintains compliant end effector characteristics
    These higher gains work with the new relative positioning system to provide
    stable, responsive control while maintaining smooth motion.
    Tested: All three joints operating smoothly with no oscillation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
    [teleop.yaml]
2026-02-19 feat(swivel): convert swivel to position control and fix Enabled→Running state
    - motor_control: populate synthetic feedback after enable so swivel
    is visible in telemetry; auto-transition base motors Enabled→Running
    once commands are flowing (fixes circular dependency with teleop)
    - hardware_jetson_rover.yaml: widen swivel soft limits to ±15 rad to
    accommodate raw encoder offset (was ±π, motor reported 7.06 rad)
    - comms/messages.rs: add Swivel command type with position/kp/kd;
    Drive command gains now use kp/kd instead of swivel velocity
    - teleop.py: swivel is now position-controlled via Z/C keys;
    add safe disable (Q×2) and safe shutdown (X) sequences
    - teleop.yaml: add driv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
    [hardware_jetson_rover.yaml]
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2026-02-23 Merge arm_teleop into teleop, fix enable safety bugs
    - Merge arm_teleop.py into teleop.py: wrist_pitch/roll/gripper controls
    added (keys 7/8, [/], -/=), full 6-joint arm_joints commands, homing
    and safe shutdown extended to all 6 arm joints, WRIST display line
    - Remove arm_teleop.py (functionality now in teleop.py)
    - teleop.yaml: extend motors.gantry/all and gantry kp/kd to 6 joints
    - Fix safety bug: reset gantry_initialized on disable/estop so motors
    don't snap back to stale positions when re-enabled after being moved
    - Fix enable reliability bug: send_keepalives() now covers arm_group
    motors so they don't hit the hardware watchdog (~100ms) while the
    enable sequence blocks on unco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
    [main.rs, teleop.py, teleop.yaml]
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2026-02-24 feat(cameras): PoE network, relay service, pointcloud prep, and SSH fixes
    Network topology:
    - Move Pi IPs to PoE Ethernet subnet (10.42.0.11-14)
    - Add camera_relay.py on Jetson: SUB from Pi PoE → PUB on all interfaces
    - Add aizee-camera-relay systemd service (deployed and running)
    - Add setup_pi_ethernet.sh to bootstrap new Pi onto PoE subnet
    - Update CLAUDE.md with new two-subnet topology and SSH patterns
    SSH:
    - Fix all Pi scripts from broken -J ProxyJump to Jetson-hop pattern
    (ssh to Jetson first, then ssh -i ~/.ssh/aizee_rover_id to Pi)
    - deploy_rpi4_camera_scp.sh: tar pipe routed through Jetson
    - deploy_all_cameras.sh: switched to _scp variant
    Pointcloud prep (rerun_bridge + camera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
    [hardware_rpi4_cam_front.yaml, hardware_rpi4_cam_left.yaml, hardware_rpi4_cam_rear.yaml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]
2026-02-24 feat(depth): fix bad optional access by rebuilding librealsense2 with RSUSB backend
    The Pi kernel (6.12.47+rpt-rpi-v8, Debian trixie) does not include hid_sensor_*
    modules required by the default librealsense2 kernel HID backend. Rebuilt with
    FORCE_RSUSB_BACKEND=ON to use libusb directly, eliminating the kernel dependency.
    - Add scripts/build_librealsense_rsusb.sh: builds v2.56.2 with RSUSB backend
    - Update cam_front serial: 039222250133 (firmware 5.17.0.10)
    - Update cam_rear serial: 036322250347 (firmware 5.17.0.10)
    - Update CLAUDE.md: fix ProxyJump→Jetson-hop SSH pattern, add NAT masquerade docs
    Depth data now flows end-to-end: ~92k valid pixels/frame, median ~0.64m,
    intrinsics correct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
    [hardware_rpi4_cam_front.yaml, hardware_rpi4_cam_rear.yaml]
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2026-02-24 fix(teleop): set battery shutdown threshold to 20V, UPS shutdown to 10V
    - Battery: voltage_min = 20.0 (matches voltage_critical) so percentage reads 0%
    at the shutdown threshold rather than at 18V
    - Add ups config section to both teleop configs: voltage thresholds for the
    Jetson UPS (3S LiPo, shutdown at 10V, warn at 10.8V, nominal at 11.7V)
    - Teleop UPS display now uses voltage thresholds from config instead of
    hardcoded percentages: OK/WARN/CRIT/SHUTDOWN states
    [teleop.py, teleop.yaml, teleop_rover_only.yaml]
2026-02-24 feat(rerun): unified 3D view with floating RGB projections and stitched pointclouds
    Each camera now gets a child entity "sensor" under world/rover/cameras/{cam_id}/
    with Transform3D (correct RDF camera orientation per yaw) + Pinhole (intrinsics).
    RGB images logged there appear as floating billboards projected from each camera
    position into the shared 3D world space.
    - build_blueprint(): replace 3D+2D-strip layout with single Spatial3DView showing
    world/** — pointclouds, RGB billboards, arm FK, LiDAR, rover body in one view
    - initialize_rerun(): log static Transform3D + default Pinhole per camera sensor
    - process_camera_message(): log color image to sensor/image for 3D projection;
    upda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
    [rerun_bridge.py]
2026-02-24 Fix Rerun bridge: timeline, camera orientation, and Transform3D API
    - Fix RotationMat3x3 AttributeError: use mat3x3= kwarg directly on
    Transform3D (Rerun 0.29.1 doesn't have rr.RotationMat3x3)
    - Fix frozen pointcloud: switch camera timeline from per-frame sequence
    ("frame") to wall-clock ("time") to match telemetry timeline; use
    local receive time to avoid Pi clock skew causing out-of-order entries
    - Fix upside-down cameras: flip color and depth images 180° before
    processing so floating RGB billboards and pointcloud geometry are
    correctly oriented
    [rerun_bridge.py]
2026-02-25 feat(arm-cameras): add D435 gripper cameras with udev-driven autostart
    Two Intel RealSense D435 cameras (USB, Jetson-direct) at the end of the
    arm looking at the gripper. Services start on plug-in and stop on unplug
    via udev device unit binding — no boot failures if cameras are absent.
    - python/nodes/arm_camera_node.py: new YAML-config-driven D435 node;
    selects camera by serial number, configurable color/depth enable
    - config/hardware_jetson_arm_cam_{left,right}.yaml: per-camera configs
    with calibrated intrinsics (left fx=384.84, right fx=382.02)
    - config/udev/99-aizee-realsense.rules: matches D435s by USB port path,
    creates /dev/realsense_arm_{left,right} and systemd device units
    -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
    [hardware_jetson_arm_cam_left.yaml, hardware_jetson_arm_cam_right.yaml, hardware_jetson_rover.yaml]
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2026-02-25 fix: CAN robustness - watchdog keepalives, enable poll, missed ticks
    - send_arm_commands: send zero-force position-hold frames to Enabled
    arm motors to prevent hardware watchdog firing before first ArmJoints
    command arrives (~100ms window)
    - enable_motor: replace fixed 20-iteration poll with 50ms time-bounded
    loop; throttle keepalives to every 5ms to reduce CAN bus congestion
    when enabling later motors in the sequence
    - main: set MissedTickBehavior::Skip on arm/base intervals to discard
    accumulated ticks after blocking enable_motor() calls
    Co-Authored-By: Claude Sonnet 4.6 <noreply@anthropic.com>
    [main.rs]
2026-02-25 feat(display): add Tufty2040 status display node
    Adds a live robot-health dashboard on a Pimoroni Tufty2040 (RP2040 +
    320×240 IPS LCD) connected to the Jetson via USB CDC serial.
    - python/nodes/display_node.py: Jetson bridge — drains motor telem
    (ZMQ :5556, 50 Hz) and UPS telem (ZMQ :5562, 1 Hz) via zmq.Poller,
    assembles compact JSON packets (mv, up, ub, me, ms), sends to
    Tufty2040 at 2 Hz over serial; auto-reconnects on serial errors
    - tufty2040/main.py: MicroPython firmware — reads newline-delimited
    JSON from USB CDC, renders voltage, battery bar, motor enable status,
    and per-motor state boxes; colour-coded by threshold
    - config/udev/99-aizee-display.rules: creates /dev/tuf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
    [hardware_jetson_rover.yaml]
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2026-02-26 fix(so101): handle encoder rollover for wrist_roll and any wrap-crossing joint
    So101Leader now maintains per-joint unwrap state (_prev_raw, _unwrap_off).
    _unwrap() detects when |delta| > 2048 (half the 4096-tick range) and
    adjusts the offset so position stays continuous across the 0/4095 boundary.
    read_unwrapped() updates this state and returns values that may exceed
    [0, 4095] after a wrap. poll() now calls read_unwrapped() so calibration
    interpolation (min_raw..max_raw) works correctly for joints whose physical
    range crosses the encoder boundary.
    so101_calibrate.py:
    - run_monitor() uses read_unwrapped() to seed state before calibration
    - Calibration capture uses read_unwrapped() and store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
    [so101_leader.py]
2026-02-26 Fix SO-101 wrist_roll encoder rollover
    Three-part fix for joints whose physical range crosses the 0/4095
    encoder boundary (e.g. wrist_roll calibrated as min_raw=3800, max_raw=200):
    1. so101_leader.py — _unwrap() now stores unwrapped values in _prev_raw
    (not physical), so delta detection stays correct after boundary crossings.
    On first read after connect(), seeds _unwrap_off for wrapped calibration
    ranges: if the initial tick is in the lower segment [0, max_raw], adds
    one full revolution so the value sits above min_raw in continuous space.
    connect() resets the unwrap state so seeding always runs on reconnect.
    poll() lifts calibration bounds into unwrapped space (mx_u = m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
    [so101_leader.py]
2026-02-26 Fix so101_teleop: ZMQ blocking crash and add robot status
    ZMQ crash (force-close after ~1 min without robot connected):
    PUSH socket default HWM=1000 fills at 20Hz in ~50s, then send_string()
    blocks indefinitely. Fixed by setting SNDHWM=2 and LINGER=0 on cmd_sock,
    and using zmq.NOBLOCK on all send_string() calls (arm_joints and enable).
    Robot connection status:
    Add robot_ok flag tracked from telemetry. _render() now shows
    "robot: connected" or "robot: offline (no telemetry)" so the user
    can tell at a glance whether the AIZEE arm is reachable.
    [so101_teleop.py]
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2026-02-26 feat(so101): 7th servo, zero/mirror keys, UPS status, fix USB CAN reset
    SO-101 arm now supports 7 servos (wrist_yaw added at ID 5, wrist_roll
    moved to ID 6, gripper to ID 7). Per-joint zero_offset and direction
    fields added to calibration JSON; Z key captures current leader pose
    as zero, M key mirrors the rover arm's actual position as zero. Both
    save to disk immediately.
    so101_teleop: add robot connection status with staleness detection
    (green/yellow/red), UPS telemetry subscriber (--ups, default :5562)
    with voltage/current/power/percentage display and OK/WARN/CRIT colour
    coding. Alignment convergence check now compares against mapped target
    instead of raw leader radians.
    reset_usb_can_ad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
    [so101_leader.py, so101_teleop.py]
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
